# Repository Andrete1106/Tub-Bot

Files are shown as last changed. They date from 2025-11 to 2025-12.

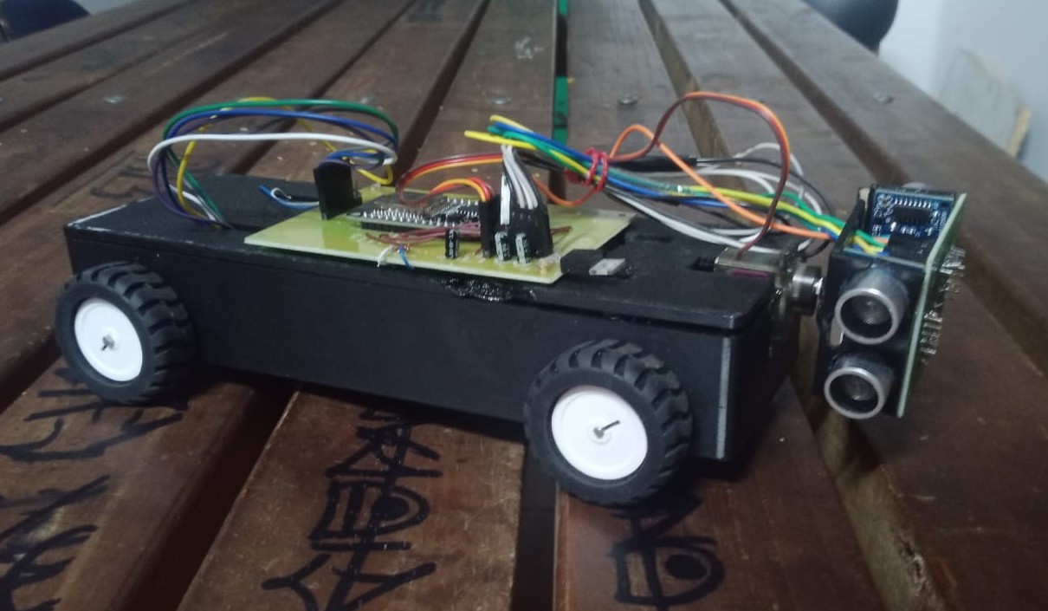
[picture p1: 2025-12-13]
Taller/Fotos y Videos/Fotos/WhatsApp Image 2025-12-12 at 5.25.53 PM.jpeg

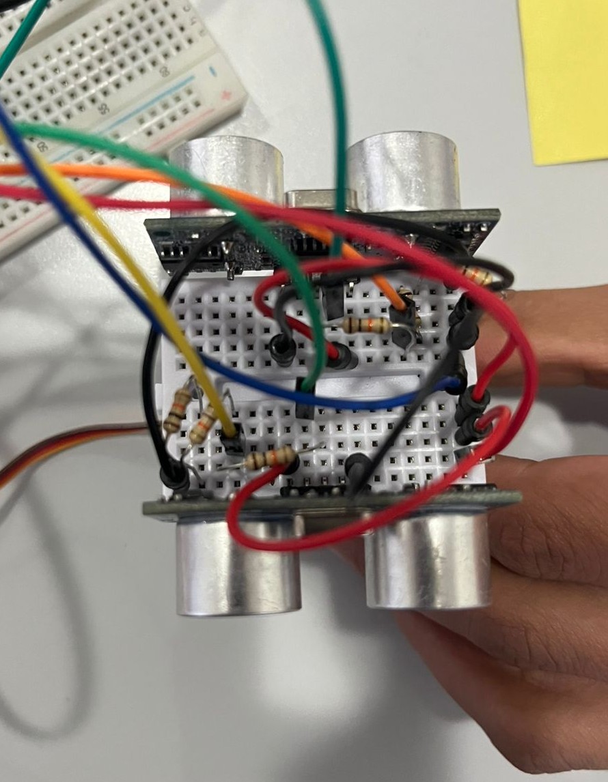
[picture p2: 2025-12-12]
Taller/Fotos y Videos/Fotos/WhatsApp Image 2025-12-07 at 12.38.35 PM (2).jpeg

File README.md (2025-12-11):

# Proyecto Tub-Bot
Repositorio para el Proyecto "Tub-Bot" correspondiente a las materias de:
- Introducción a Ingeniería Electrónica 
- Taller de Electrónica

**Universidad Nacional de Colombia**

## **Integrantes**
- Andres David Hincapié Álvarez (Ingeniería Electrónica)  
- Samuel Alejandro Bulla Fiquitiva (Ingeniería Electrónica)
- Juan Jose Aleman Martinez (Ingeniería Electrónica)
- Camilo Andrés Triana Ortiz (Ingeniería Mecatrónica)
- Ricardo Javier Rivas Sabogal (Ingeniería Electrónica)
- Luis Armando Berrocal Estrada (Ingeniería Electrónica)

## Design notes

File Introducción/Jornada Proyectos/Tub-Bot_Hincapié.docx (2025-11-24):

Título del proyecto | Tub-Bot
Autor(a) / correo / carrera que cursa ó Lista que incluya a las personas integrantes del equipo / correo / carrera que cursa Ejemplo: Patricia Perez Gabil Roso / pperezgar@unal… / Ingeniería civil | Juan Jose Aleman Martinez / jualemanm@unal.edu.co / Ingeniería Electrónica Samuel Alejandro Bulla Fiquitiva / sbullaf@unal.edu.co / Ingeniería Electrónica Ricardo Javier Rivas Sabogal / rrivass@unal.edu.co / Ingeniería Electrónica Luis Armando Berrocal Estrada / lberrocale@unal.edu.co / Ingeniería Electrónica Andrés David Hincapié Álvarez / anhincapiea@unal.edu.co / Ingeniería Electrónica

Resumen en un solo párrafo

(de 200 a 250 palabras)

El proyecto consiste en el desarrollo de un robot diseñado para desplazarse dentro de tuberías matrices y secundarias del sistema de acueducto, cuyo propósito es inspeccionar internamente la red y detectar, con alta precisión, grietas, fisuras o daños estructurales, sin realizar reparaciones directas. A diferencia de los métodos tradicionales basados en geófonos o georadares, que dependen del sonido del flujo de agua y presentan limitaciones frente a microfisuras o estructuras complejas, este prototipo permite observar el interior del conducto en condiciones sin flujo de agua, lo que incrementa la exactitud en la localización de fallas. El robot incorpora cámaras y sensores que generan un registro visual y digital del estado interno, facilitando que los equipos de acueducto planifiquen intervenciones más eficientes y eviten excavaciones innecesarias. Su capacidad de desplazamiento controlado ofrece una alternativa accesible frente a los robots modulares comerciales, que suelen tener altos costos y restricciones en diámetros menores a 100 mm. Gracias a su enfoque preventivo, este sistema mejora la gestión del mantenimiento, reduce el tiempo de diagnóstico y contribuye indirectamente a disminuir pérdidas de agua tratada al identificar oportunamente daños que, de no detectarse, podrían evolucionar en fugas mayores. En conjunto, el proyecto propone una solución tecnológica práctica, de bajo costo relativo y alineada con la necesidad de modernizar la infraestructura de inspección del acueducto de Bogotá.
Palabras clave | - Detección de daños - Inspección interna - Robot de tuberías - Tuberías matrices - Tuberías secundarias - Grietas - Fisuras - Microfisuras - Fugas - Agua potable - Acueducto - Desplazamiento controlado - Sensores - Cámara interna - Localización de averías - Diagnóstico - Sistema inteligente - Redes subterráneas - Mantenimiento preventivo - Pérdidas técnicas - Agua no contabilizada - Eficiencia operativa - Red de distribución - Bogotá - Inspección robotizada - Autonomía - Precisión

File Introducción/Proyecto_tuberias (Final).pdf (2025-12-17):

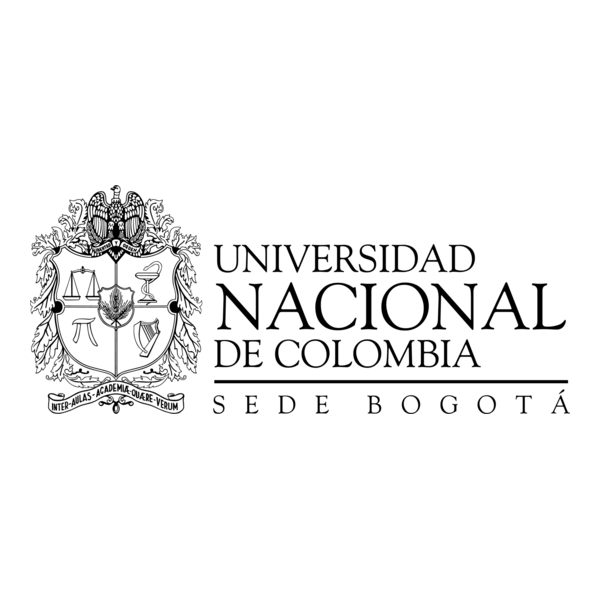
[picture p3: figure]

## SISTEMA INTELIGENTE EN DETECCION DE ´

DANOS EN TUBER ˜ | ÍAS

### Juan Aleman´

Andres Hincapi ´ | é

### Luis Berrocal Samuel Bulla Ricardo Rivas

### Universidad Nacional de Colombia

Introduccion a la ing. Electr ´ | onica ´

### Facultad de Ingenierıá Bogota D.C. ´

2025

Resumen—A partir del objetivo de desarrollo
sotenible numero seis, ´ | ”agua limpia y saneamien-
to” [1], pretendemos que por medio de nuestro prototipo, se logre implementar una metodologıá
mas efectiva en la detecci ´ | on de da ´ | nos en las redes ˜
de tuberıas locales, y asi mitigar el desperdicio de ´ agua en las ciudades y ofrecer un uso mas eficien- ´ te de este recurso; queremos que al introducir el dispositivo dentro de las tuberıas este sea capaz ´ de escanear las afectaciones y logre identificar la zona exacta en donde ocurrio el dano. ˜
I. Estado del Arte
Existen distintos sistemas los cuales buscan satisfacer la necesidad comun de identificar ´ la zona en la que una tubería se encuentra danada por lo que los hemos clasificado en tres ˜ grupos.
Sondas: Este sistema trata, en introducir un dispositivo que, generalmente se encuentra cableado semejante a un endoscopio por lo que no se facilita mucho su movilidad en entornos complejos y depende en gran medida de la longitud de sus cables en consecuencia ofrece una solucion parcial y bastante limitada. ´ Sensores independientes: Este sistema abarca bastantes tecnicas las cuales a par- ´ tir de variables analogicas como la detec- ´
cion ultras ´ | onica, la termograf ´ | ía infrarroja,
los rayos x e incluso las corrientes de Foucault ; son capaces de elaborar un modelo 3d de la tuberías, sin necesidad de ser destructivas por lo que facilita bastante los costes en reparacion,su desventaja radica ´ en su falta de precision en situaciones de ´ mayor profundidad y que se exponen al ruido/interferencias en el ambiente. Robots modulares: Estos sistemas toman grandes rasgos de los anteriores, con la ventaja de que ofrecen una mayor autonomía y mejor control de lo que está ocurriendo dentro del conducto,algunos ejemplos de ellos son el robot Pipe dream y el robot PIRATE quienes se adaptan a tubería y pueden desplazarse dentro de ella. Su mayor dificultad son los altos costos y su limitacion en cuanto a que tan ´
estrecho es el diametro de la tuber ´ | ía en
sí(<100mm)

II. Justificacion´
El prototipo permite reducir significativamente el desperdicio de agua en Bogotá
al localizar fugas y danos en las tuber ˜ | ías
con mayor rapidez y precision que las ´ tecnicas actuales. Al detectar los puntos ´ exactos de falla, se evitan excavaciones innecesarias y se logra un ahorro economico ´ directo para la Empresa de Acueducto, ademas de un importante beneficio am- ´ biental al evitar que se desperdicie tanta agua.Actualmente, la forma tradicional de reparar tuberías genera multiples proble- ´ mas a los habitantes de la ciudad: suspensiones del servicio que duran varios días, cierre prolongado de vías, aumento de los trancones y deterioro acelerado de las calles. Estas intervenciones afectan la movilidad, la calidad de vida y la imagen de la ciudad.Nuestro proyecto propone una solucion eficaz y de bajo costo, construida ´ con componentes disponibles localmente, que reduce drasticamente los tiempos y ´ costos de inspeccion. Al minimizar las ex- ´ cavaciones a ciegas, no solo se optimizan los recursos publicos, sino que se previe- ´ nen riesgos mayores como hundimientos, colapsos de redes e inundaciones en el sistema.

III. Problematica ´

En el 2024 en bogota se desperdiciaron ´ aproximadamente 89 millones de metros cubicos de agua potable , debido princi- ´ palmente a las conexiones defectuosas y a las tuberías danadas dentro de la red de ˜ acueducto de la ciudad, esta cifra equivale aproximadamente al consumo de agua de un mes en la ciudad por lo que su cifra es alarmante dentro de un contexto en el que el agua es un recurso limitado el cual por distintas circunstancias que se han presentando nuestros embalses han disminuido su densidad. El agua es un recurso renovable en la medida en que su uso no exceda la tasa de renovacion natu- ´ ral y de por sí nosotros los humanos dependemos en gran medida de este recurso para nuestra supervivencia meramente individual; nos beneficiamos principalmente de el agua dulce la cual representa solo 2.5% de la cantidad total terrestre ´ y de la cual no tenemos todo su acceso ya que el 68.7% de esa agua se encuentra congelada, el 30.1% es subterranea y ´ nos quedamos con un restante global de aproximadamente 1.2% que mantiene a 8 millones de personas con vida por lo que es una problematica bastante seria el ´ hecho de que por factores estrategicos y ´

logísticos en la red de distribucion del ´ agua estemos presentando tantas perdidas ´ de un recurso tan valioso como este.
La verdadera problematica no radica en ´ que las tuberías se rompan ya que no necesariamente dicho rompimiento puede deberse a la obsolescencia del material, tambien puede presentarse por movi- ´ mientos en la tierra o por golpes de ariete al tratarse de un material el cual está expuesto a un flujo y friccion constante ´ es casi inevitable que se presente algun´ desgaste, la problematica que hemos ana- ´ lizado esta inmersa en el hecho de las ´ practicas actuales no generan la suficiente ´ eficacia como para detectar si una tubería se encuentra rota, en bogota se utilizan ´
comunmente los ge ´ | ofonos y georadares ´
los cuales por medio del sonido que genera el agua en una fuga identifican donde se encuentra el dano a la red, ahora bien ˜ estas tecnicas no son lo suficientemente ´ buenas al momento en que se presentan microfisuras que a su vez generan goteos o al momento en que una fuga posee un sistema complejo en su deteccion ya que un ´ sonido no es una senal tan exacta si se tra- ˜ ta de una red mas compleja que involucra ´
mas tuber ´ | ías.Ahora bien ¿como entonces

se disena un sistema inteligente capaz de ˜

solucionar un problema complejo como

el desperdicio de agua potable a traves´

del dano en una tuber ˜ | ía subterranea?. ´
IV. | Marco teorico ´
La inspeccion del estado estructural de las ´ tuberías de agua potable es un componente esencial para la empresa de acueducto y alcantarillado de Bogota,la cual ´ cuenta con líneas principales y secundarias de diametros superiores a 6 pulgadas. ´ Estas tuberías estan sometidas a presio- ´ nes variables, cargas del terreno, procesos de corrosion, vibraciones y desgastes del ´ material, factores que pueden ocasionar danos en los conductos,facilitando las fil- ˜ traciones de agua . La deteccion temprana ´
de estos danos permite reducir p ˜ | erdidas ´
de agua, optimizar el mantenimiento y garantizar la continuidad del servicio. Sin embargo, muchas de las fallas internas no son visibles, al encontrarse enterradas a una profundidad aproximada de un metro , se hace necesaria la inspeccion´ directa dentro del conducto. Aunque exis-
ten metodos de inspecci ´ | on externa como ´
medicion de presi ´ | on, mapeo ac ´ | ustico o ´
sondas con camaras introducidas ,estas ´ tecnicas tienen limitaciones, especialmen- ´ te en tuberías enterradas. Por esta razon, ´ en nuestro proyecto planteamos recurrir a la apertura controlada de un tramo de
tubería ,fuera de operacion y as ´ | í intro-
ducir nuestro dispositivo de exploracion´ interna.Para ello contamos con dos formas de recolectar informacion dentro del con- ´
ducto una es a traves de un m ´ | odulo de ´
camara, la cual vigilar ´ | a durante el tramo ´
de recorrido ,si se observa algun da ´ | no evi- ˜
dente y de facil identificaci ´ | on; otra es por ´
medio de sensores ultrasonido los cuales son capaces de detectar pequenas pertur- ˜
baciones en el diametro de la tuber ´ | ía, esto
es posible gracias a que en su funcionamiento emiten y captan senales de sonido ˜ las cuales rebotan contra las paredes del conducto ,si hablamos de una senal cons- ˜ tante(diametro constante)los valores que ´ arrojen estos sensores deben ser iguales durante el tramo donde se escanee, de no ser así indica que el conducto pre-
senta una perturbacion la cual est ´ | a in- ´
terviniendo y que generalmente representa un dano en su estructura.Todo este ˜ procesamiento de informacion va a ser ´ transportada vía cable,la cual conectara al ´ prototipo con un servidor el cual estará recibiendo la transmision de la informa- ´
cion en tiempo real y por el cual tambi ´ | en´
se podra dar ´ | ordenes de movilizaci ´ | on al ´
prototipo una vez dentro. La transmision´ de informacion v ´ ía cable ofrece algunas ventajas ,una de ellas es su capacidad para ofrecer un mejor transporte de las senales recolectadas sin que el ruido ex- ˜ terno las afecte y se pierda informacion´ en el trayecto, si hablamos de un ambiente cerrado, hermetico y que en muchos casos ´ se compone de una estructura metalica, ´ se crea una jaula de faraday la cual im-
posibilita la transmision de informaci ´ | on´
por senales electromagn ˜ | eticas por lo que ´
la alternativa bluetooth no sería la mas´ adecuada en estos casos. Finalmente todo se encontrara en un solo modelo el cual integrara ambas formas de recolectar la ´
informacion, mientras que el m ´ | | odulo de ´
la camara recolecta la informaci ´ | | on visual ´
,el modulo de sensor ultrasonico recoge la ´
informacion estructural de la tuber ´ | | ía, am-
bos tipos de datos facilitaran abarcar m ´ | as´

terreno en cuanto al tipo de dano que se ˜ presenta,ya que en realidad no se puede determinar facilmente la causa si solo se ´ tiene un vistazo inicial del conducto. La geometría cilíndrica de un tubo no permite un desplazamiento sencillo dentro de este, si se piensa de la forma tradicional como en una superficie plana,cuenta con varias intersecciones y cambios en
los diametros de las tuber ´ | ías por lo que
se necesita repensar un modelo el cual sea capaz de adaptarse a estos cambios de diametro y puede flexionarse en las ´ diferentes intersecciones, de lo contrario no sobrevivira a este tipo de condiciones. ´
V. Hipotesis ´
A partir de un prototipo que integre una esp32-cam y un par de sensores ultrasonido,que envían informacion v ´ ía cable a un servidor capaz de interpretar y transmitir datos en tiempo real;se logre implementar una metodología mas eficiente en la ´
deteccion de da ´ | nos a las redes de tuber ˜ | ía
en Bogota y en consecuencia se disminuya ´ el desperdicio de agua en la ciudad.
VI. | Objetivo general
Identificar | eficazmente | los | danos | en ˜

una tubería implementando un prototipo

inteligente

VI-A. Objetivos especificos:
1. Localizar la zona en donde se encuentra la avería
2. Desplazarse de forma controlada por el conducto
3. Comunicar el dano encontrado ˜

VII. Metodología
El desarrollo del prototipo se llevo a cabo ´ mediante un proceso iterativo, en el cual fue necesario ajustar varias decisiones de disenõ debido a las condiciones físicas y operativas de una tubería de seis pulgadas. Inicialmente, se planteo construir un modelo compac- ´ to que pudiera desplazarse facilmente por el ´ interior del conducto; sin embargo, durante las primeras etapas se presentaron percances relacionados con las dimensiones internas, el espacio util disponible y la interferencia ge- ´ nerada por elementos como cables, sensores y mecanismos de movilidad. Estos inconvenientes obligaron a redisenar la estructura y a ˜ reorganizar la distribucion de los componentes ´ electronicos.Una de las decisiones clave fue ´ la incorporacion de una ESP32-CAM como ´ unidad principal de captura de imagenes. Este ´
modulo se seleccion ´ | o debido a que integra la ´
camara OV2640, lo que facilit ´ | o su implementa- ´
cion sin necesidad de m ´ | odulos adicionales. Su ´
tamano compacto, conectividad inal ˜ | ambrica y ´
facilidad de programacion permitieron agilizar ´ la etapa de pruebas y optimizar la adquisicion´ de imagenes durante el desplazamiento del ´ prototipo. Para la deteccion de perturbaciones ´
en el diametro interno de la tuber ´ | | ía, se integra-
ron dos sensores ultrasonicos montados sobre ´ un servo motor capaz de ejecutar un giro de
180°. Durante la fase de diseno se evidenci ˜ | ó
que, al girar el sensor en una superficie circular, se generaban puntos ciegos que impedían obtener una lectura completa del entorno. Por esta razon, fue necesario incluir dos sensores ´ en vez de uno, ubicados de forma simetrica, ´ de manera que el barrido cubriera totalmente
la seccion del conducto. Esta configuraci ´ | | on´
permitio obtener mediciones m ´ | as estables y ´
precisas en cada rotacion. ´
El sistema de movilidad del prototipo se di-
senõ mediante cuatro motores de tracci ´ | on, ins- ´
talados en configuracion tipo veh ´ | ículo para
garantizar un desplazamiento estable dentro de la tubería. Cada par de motores fue controlado mediante un driver L298N, permitiendo así la manipulacion independiente del movi- ´ miento.Con el fin de optimizar el desempenõ general del sistema, se decidio implementar ´ dos unidades ESP32 independientes: una dedi-
cada unicamente a la c ´ | amara y la transmisi ´ | on´
de imagenes, y otra encargada del control de ´ motores, sensores ultrasonido y servo. Esta se-
paracion permiti ´ | o distribuir la carga de proce- ´
samiento, evitando saturacion en un ´ | unico mi- ´
crocontrolador y logrando un funcionamiento
mas fluido, especialmente en la transmisi ´ | on de ´
vídeo.
Todos los componentes electronicos se inte- ´ graron en una placa PCB disenada a medida, ˜ lo que permitio reducir el cableado, asegurar ´ conexiones mas firmes y facilitar el ensamblaje ´ dentro del prototipo. Finalmente, el chasis fue impreso en 3D utilizando filamento PETG, material elegido por su alta resistencia mecanica, ´ durabilidad, tolerancia a la humedad y estabilidad dimensional, características esenciales para operar dentro de un entorno cerrado y
potencialmente humedo como una tuber ´ | | ía de
agua potable.

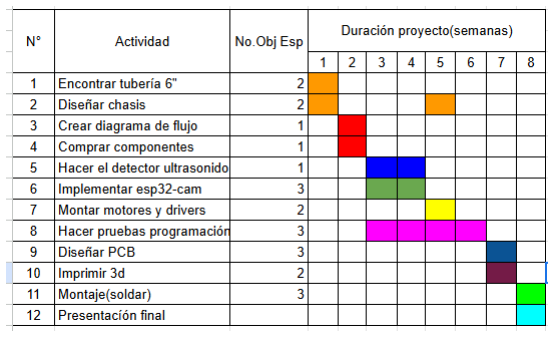
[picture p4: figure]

VIII. Cronograma de actividades

Referencias

[1] O. | de | las | Naciones | Unidas. | (2015) | Agua
y saneamiento. Accedido: 10/03/2025. [Online]. Available: https://www.un.org/sustainabledevelopment/es/water-and-sanitation/ (https://www.un.org/sustainabledevelopment/es/water-and-sanitation/)
[2] R. USA. (2025) Laser pipe profiling applications. Accedido: 10/03/2025. [Online]. Available: https: //rauschusa.com/products/cctv-inspection/availabl e-applications/laser-pipe-profiling/ (https://rauschusa.com/products/cctv-inspection/available-applications/laser-pipe-profiling/)
[3] JettyRobot. (2025) Robotic solutions for pipe inspection. Accedido: 10/03/2025. [Online]. Available: https://www.jettyrobot.com/
[4] D. Henares. (2023) Robot de inspeccion de ca ´ | ner ˜
| | | | | | ías.
Accedido: 10/03/2025. [Online]. Available: https: //www.desatascoshenares.com/blog/robot-inspeccio n-canerias/ (https://www.desatascoshenares.com/blog/robot-inspeccion-canerias/)
[5] A. M. de Bogota. (2024) ´

Índice de perdida o ´
desperdicio de agua en bogota. Accedido: 10/03/2025. ´ [Online]. Available: https://bogota.gov.co/mi-ciudad/habitat/indice-de-perdida-o-desperdicio-agua-en-b ogota-es-estandar-acueducto (https://bogota.gov.co/mi-ciudad/habitat/indice-de-perdida-o-desperdicio-agua-en-bogota-es-estandar-acueducto)
[6] U. de los Andes. (2023) 37% del agua en bogot
| | | | | | á
se pierde. Accedido: 10/03/2025. [Online]. Available: https://www.uniandes.edu.co/es/noticias/ingenieria/37-del-agua-en-bogota-se-pierde (https://www.uniandes.edu.co/es/noticias/ingenieria/37-del-agua-en-bogota-se-pierde)
[7] E. de Acueducto y Alcantarillado de Bogota. (2024) ´ Mapa del acueducto. Accedido: 10/03/2025. [Online]. Available: https://www.acueducto.com.co/wps/portal/EAB2/Home/acueducto-y-alcantarillado/la-infraestructuraAcueducto/Mapa-Acueducto (https://www.acueducto.com.co/wps/portal/EAB2/Home/acueducto-y-alcantarillado/la-infraestructuraAcueducto/Mapa-Acueducto)
[8] F. Aquae. (2023) ¿que cantidad de agua dulce hay en ´ el planeta? Accedido: 10/03/2025. [Online]. Available: https://www.fundacionaquae.org/que-cantidad-de-agua-dulce-hay-en-el-planeta/ (https://www.fundacionaquae.org/que-cantidad-de-agua-dulce-hay-en-el-planeta/)

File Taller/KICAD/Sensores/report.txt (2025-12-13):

Actualizado Conn_01x05 de J4_coneccion_esp a J4_coneccion_esp1.
Actualizado Conn_01x02 de J_pwr a J_pwr1.
Anotación completada.
Anotación completada.

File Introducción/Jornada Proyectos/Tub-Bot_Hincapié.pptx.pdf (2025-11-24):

# Introducción

El sistema de acueducto de Bogotá enfrenta un desgaste progresivo debido a la antigüedad de gran parte de su infraestructura, lo que favorece la aparición de grietas, fisuras y deterioros internos que suelen pasar desapercibidos hasta convertirse en fugas significativas. Los métodos tradicionales de inspección —como geófonos o georadares— presentan limitaciones importantes, especialmente en el caso de microfisuras, tuberías de difícil acceso o condiciones sin flujo de agua, donde la detección se vuelve imprecisa y lenta. Esta situación contribuye a un incremento en las pérdidas técnicas de agua potable, que representan un problema operativo y económico para la ciudad, pues la identificación tardía de fallas obliga a intervenciones más costosas y a excavaciones que afectan la movilidad y el entorno urbano. Frente a este escenario, el proyecto propone el desarrollo de un robot capaz de desplazarse dentro de tuberías matrices y secundarias para inspeccionarlas visualmente desde el interior, registrando daños (se usa sin flujo de agua) y sin reemplazar directamente los métodos de reparación. Este enfoque ofrece una alternativa más accesible que los robots comerciales de alto costo, un tamaño adaptado para tuberías más reducidas al tiempo que mejora la precisión del diagnóstico y apoya la toma de decisiones antes de que las averías evolucionen en fugas mayores. En conjunto, el proyecto busca fortalecer las estrategias de mantenimiento preventivo y contribuir a la reducción de pérdidas de agua en la ciudad mediante una inspección más eficiente y tecnológicamente viable.

# Objetivos

Objetivo general
Desarrollar un sistema robótico capaz de identificar de manera eficiente y precisa los daños internos en tuberías matrices y secundarias, con el fin de mejorar la detección temprana de averías y apoyar la reducción de pérdidas de agua potable en Bogotá.
Objetivos específicos
1. Diseñar un robot capaz de desplazarse de forma estable dentro de tuberías matrices y secundarias.
2. Detectar y registrar visualmente grietas, fisuras y daños internos.
3. Localizar con precisión la posición de las averías para facilitar intervenciones externas.
4. Reducir el tiempo y la dificultad de las inspecciones respecto a métodos tradicionales y mejorar la eficiencia del diagnóstico de daños en la red de acueducto
5. Contribuir a la disminución de pérdidas técnicas de agua potable en Bogotá mediante la detección temprana de averías
6. Proponer una solución de bajo costo relativo, tamaño adaptado a las necesidades.

# Resultados Esperados

# Fractal

# Errores

A lo largo del desarrollo del proyecto hemos identificado varios errores que han influido en el avance y el alcance final de la propuesta. En primer lugar, planteamos un proyecto demasiado ambicioso, especialmente al intentar cubrir tuberías con desviaciones verticales, lo cual superaba nuestra capacidad técnica y los recursos disponibles, obligándonos a reducir su alcance hacia escenarios más realistas. También seleccionamos algunos materiales que, aunque parecían adecuados, no se adaptaron correctamente al prototipo debido a limitaciones de espacio que no habíamos contemplado, sumado a que omitimos la compra de adaptadores esenciales para integrar componentes específicos. Otro error importante fue la elección de un microcontrolador incompatible con otros elementos electrónicos, generando conflictos de conexión y alimentación que no previmos en la planeación inicial. Además, partimos de la idea equivocada de que la electrónica era un área de aplicación limitada, lo que nos llevó a subestimar la complejidad real de integrar sensores, motores y controladores en un espacio reducido. A esto se añadió que subestimamos los tiempos necesarios para desarrollar el proyecto con calma, lo que provocó retrasos y presión innecesaria. Finalmente, durante las primeras etapas tuvimos dificultades para organizarnos y entendernos como equipo, lo que afectó la coordinación y la toma de decisiones. Todos estos aspectos nos permitieron reconocer la importancia de una planificación detallada, una comunicación efectiva y una evaluación técnica más rigurosa desde el inicio.

# Tub-Bot

Juan Jose Aleman Martinez
jualemanm@unal.edu.co

Andrés David Hincapié Álvarez anhincapiea@unal.edu.co

Samuel Alejandro Bulla Fiquitiva sbullaf@unal.edu.co

Luis Armando Berrocal Estrada lberrocale@unal.edu.co

Ricardo Javier Rivas
Sabogal
rrivass@unal.edu.co
- Detección precisa de daños internos:
El robot permitirá identificar grietas, fisuras y deterioros en tuberías matrices y secundarias, incluso sin flujo de agua.
- Localización exacta de averías:
Se espera obtener una ubicación clara y puntual de los daños para facilitar intervenciones y evitar excavaciones innecesarias.
- Registro visual y digital confiable:
El sistema generará imágenes y datos que documenten el estado interno de la red y mejoren la toma de decisiones.
- Prototipo funcional y eficiente:
El robot ofrecerá desplazamiento estable, reducción de tiempos de inspección y una alternativa de bajo costo frente a equipos comerciales.

# Fractal

## Jornada de Proyectos y Prototipos

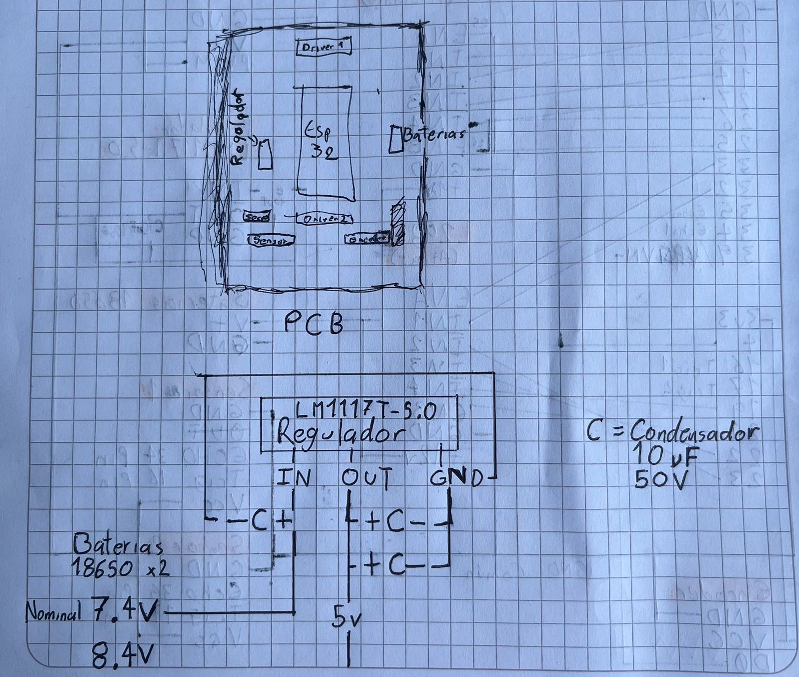
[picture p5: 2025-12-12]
Taller/Fotos y Videos/Fotos/WhatsApp Image 2025-12-07 at 12.38.35 PM.jpeg

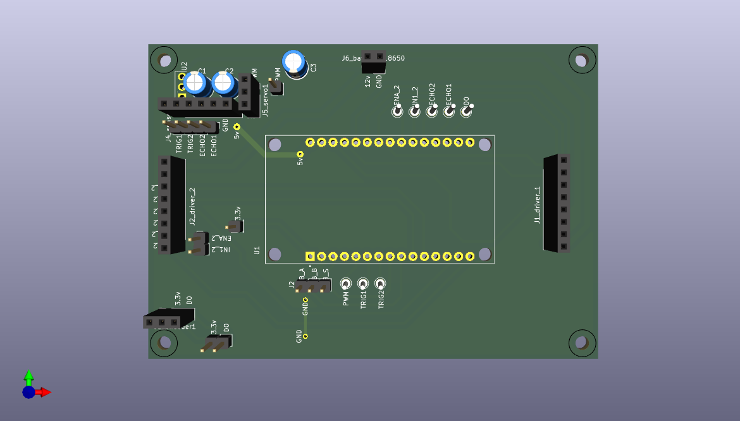
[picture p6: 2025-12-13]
Taller/KICAD/Principal/Pcb_Principal.png

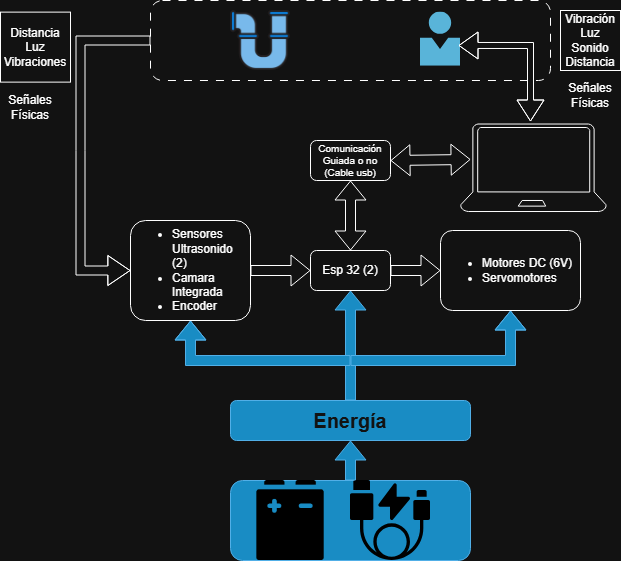
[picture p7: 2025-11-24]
Taller/Diagramas/Diagrama Caja Negra.png

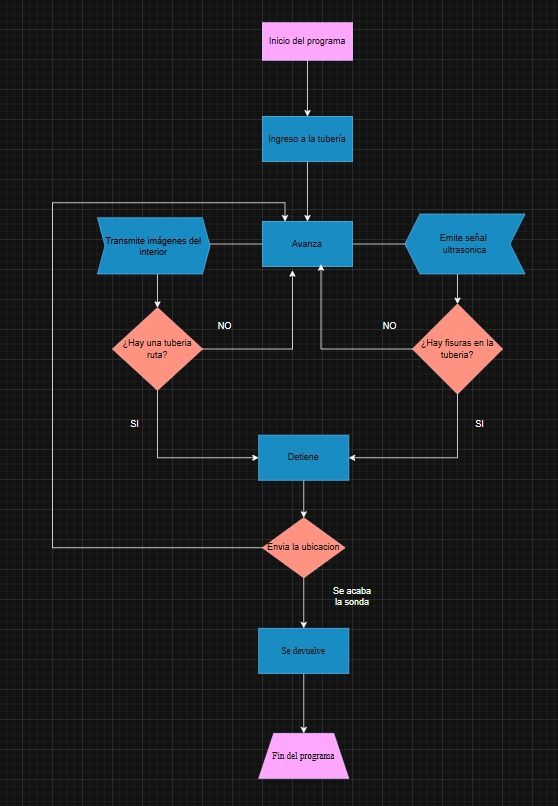
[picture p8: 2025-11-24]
Taller/Diagramas/Diagrama Flujo.jpg

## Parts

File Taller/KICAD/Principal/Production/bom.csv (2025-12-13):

Designator | Footprint | Quantity | Value | LCSC Part #
C1, C2, C3 | CP_Radial_D5.0mm_P2.50mm | 3 | C_Polarized
J1_DRIVER_1, J2_DRIVER_2 | PinSocket_1x08_P2.54mm_Vertical | 2 | Conn_01x08
J3_ENCODER1, J5_SERVO1 | PinSocket_1x03_P2.54mm_Vertical | 2 | Conn_01x03
J4_SENSORES1 | PinSocket_1x06_P2.54mm_Vertical | 1 | Conn_01x06
J6_BATERIAS_18650 | PinSocket_1x02_P2.54mm_Vertical | 1 | Conn_01x02
U1 | MODULE_ESP32_DEVKIT_V1 | 1 | ESP32-DEVKIT-V1
U2 | SIPAK_Vertical | 1 | LM1117DT-5.0

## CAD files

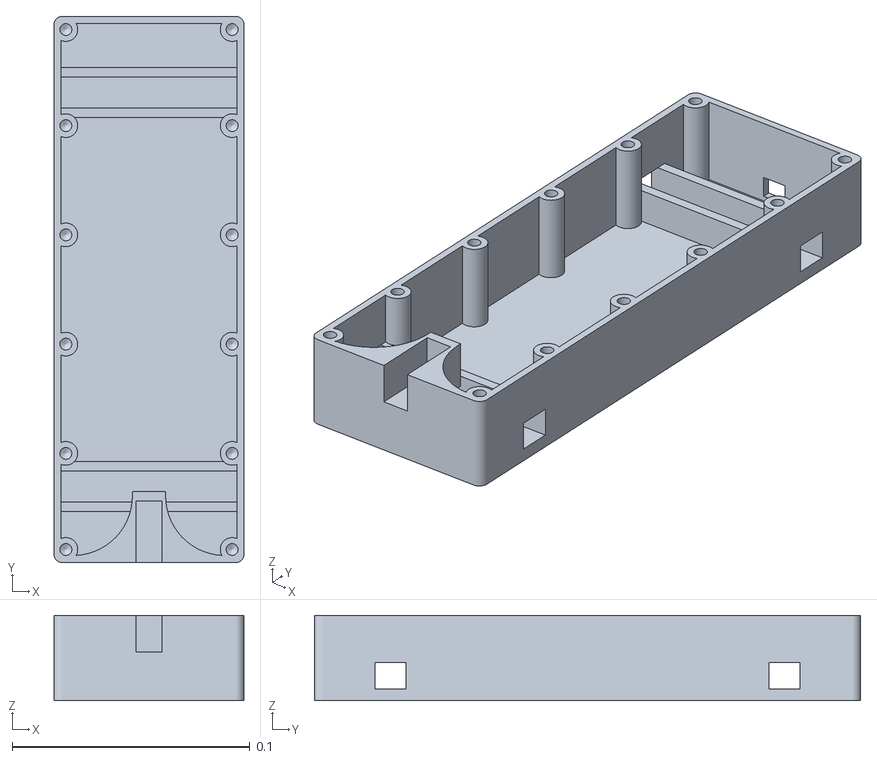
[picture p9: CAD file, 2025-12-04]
Taller/Diseño/Case/Cuerpo-Carcaza.stl
0.08 x 0.23 x 0.036

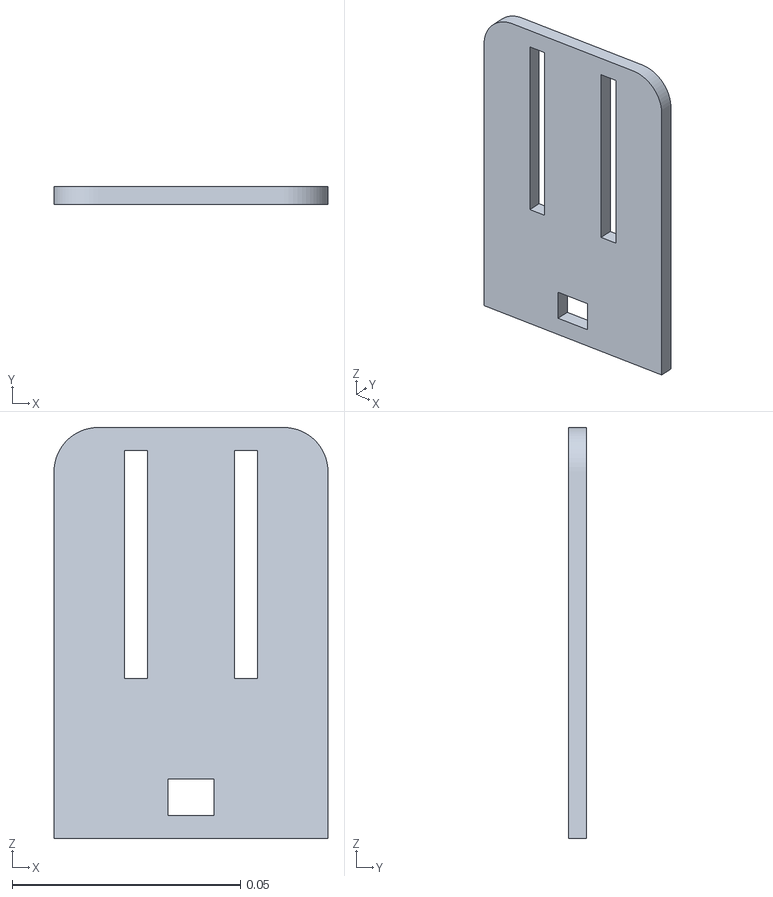
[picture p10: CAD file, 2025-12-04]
Taller/Diseño/Case/EncajeESP32.stl
0.06 x 0.004 x 0.09

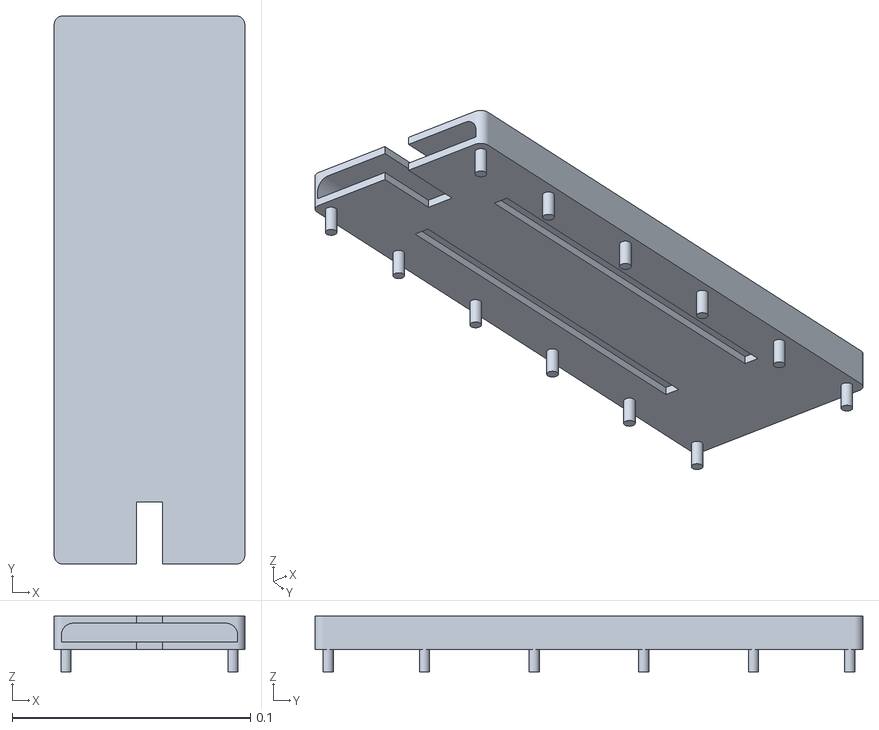
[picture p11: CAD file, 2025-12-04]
Taller/Diseño/Case/Tapa.stl
0.08 x 0.23 x 0.0235

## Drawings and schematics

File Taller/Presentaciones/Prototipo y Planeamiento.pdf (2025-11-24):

# PROYECTO FINAL

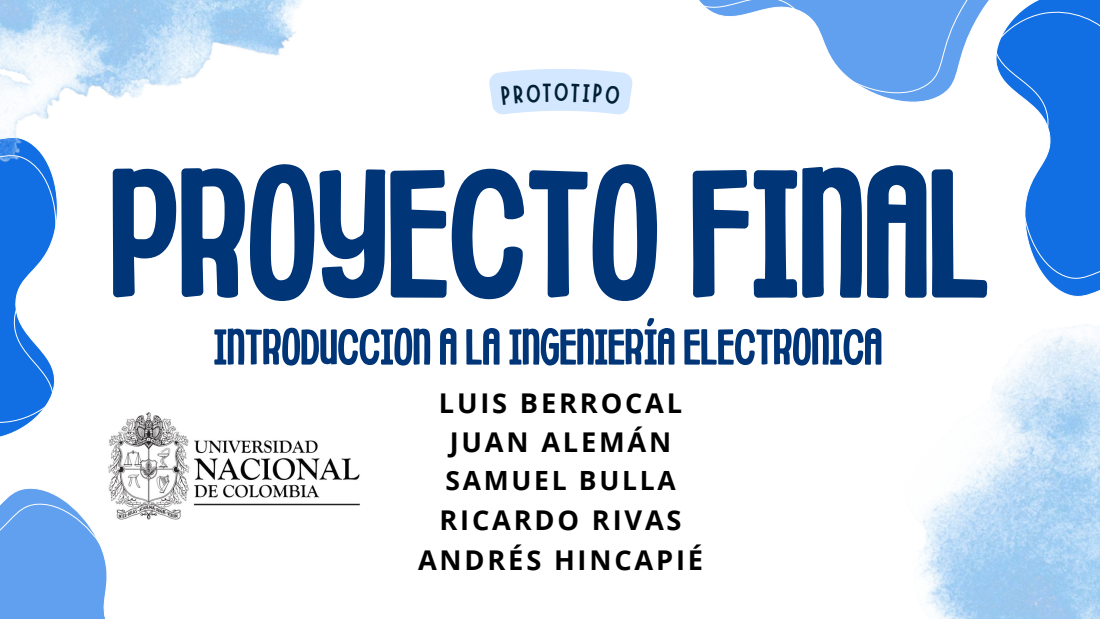
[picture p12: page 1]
INTRODUCCIONALAINGENIERÍAELECTRONICA; PROTOTIPO; LUIS BERROCAL JUAN ALEMÁN SAMUEL BULLA RICARDO RIVAS ANDRÉS HINCAPIÉ

# RESUMEN DE CONTENIDOS

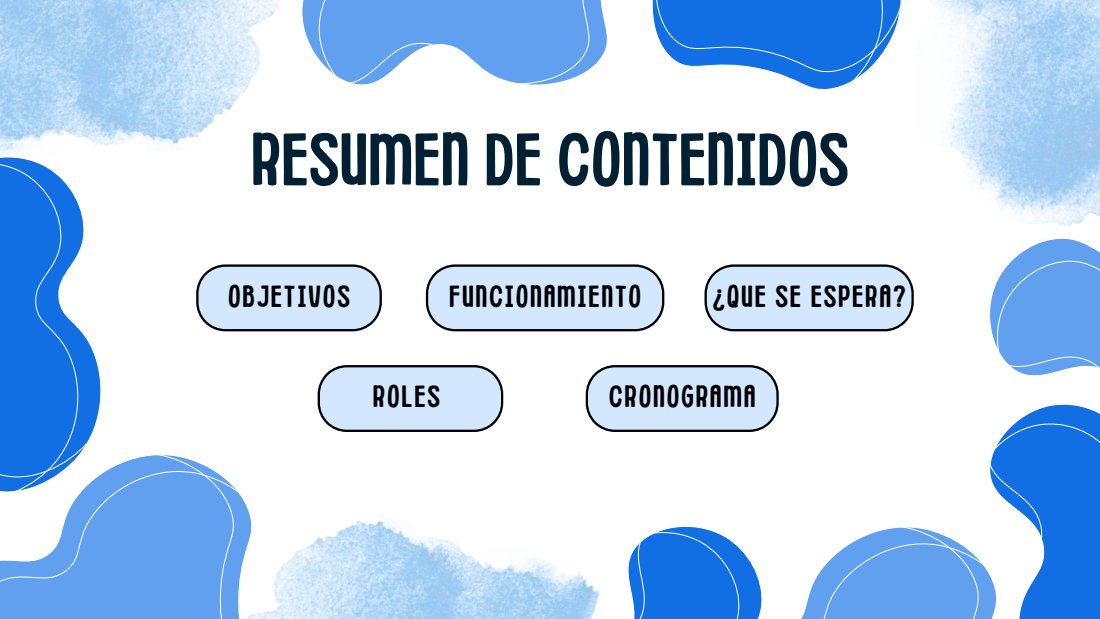
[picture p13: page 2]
ROLES; OBJETIVOS; FUNCIONAMIENTO; ¿QUE SE ESPERA?; CRONOGRAMA

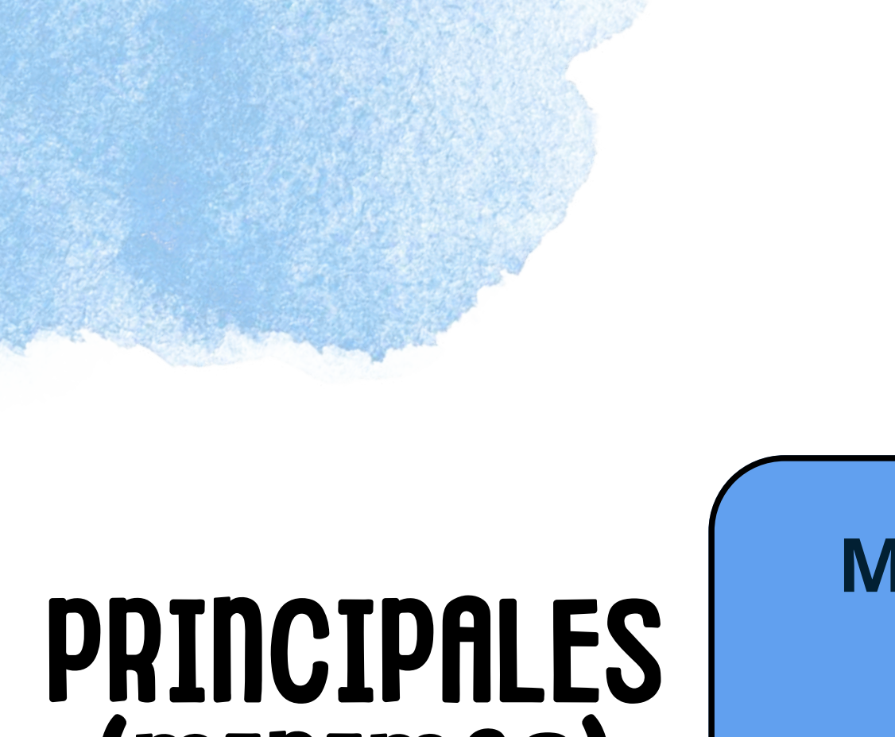
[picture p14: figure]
PRINCIPALES
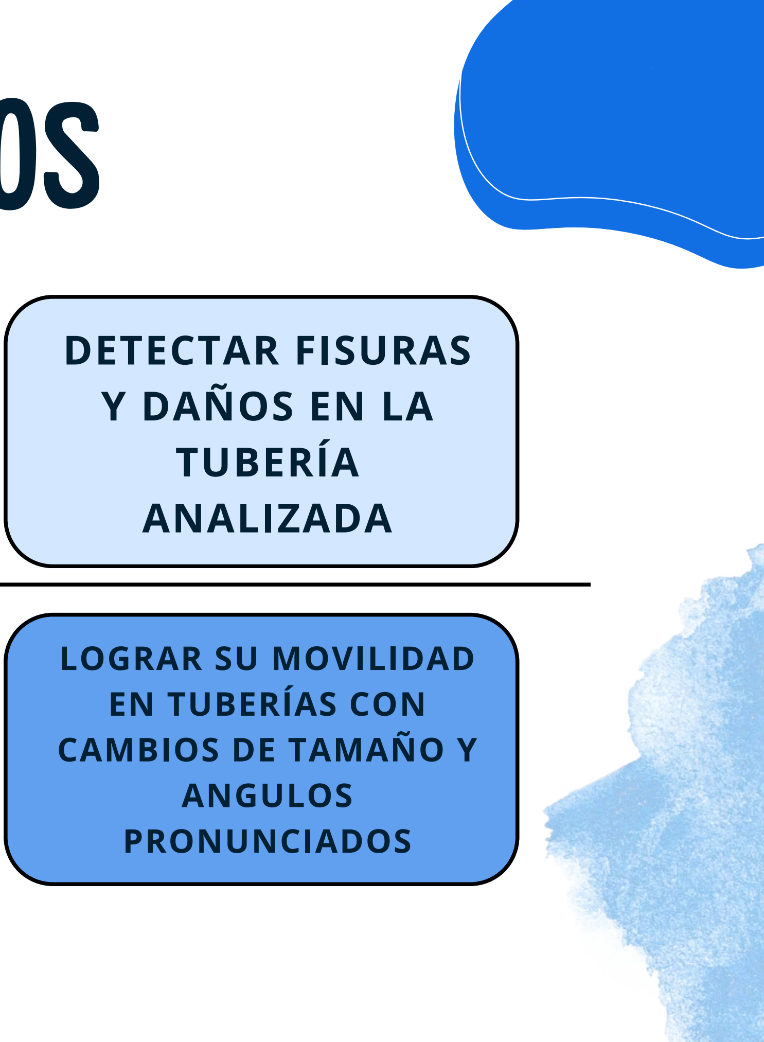
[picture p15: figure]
LOGRAR SU MOVILIDAD EN TUBERÍAS CON CAMBIOS DE TAMAÑO Y ANGULOS PRONUNCIADOS; DETECTAR FISURAS Y DAÑOS EN LA TUBERÍA ANALIZADA

# OBJETIVOS

## OPTIMIZAR LA ENERGÍA PARA SU FUNCIONAMIENTO

## MOVILIZARSE POR LA TUBERÍA

# (MINIMOS)

# SECUNDARIOS

# FUNCIONAMIENTO

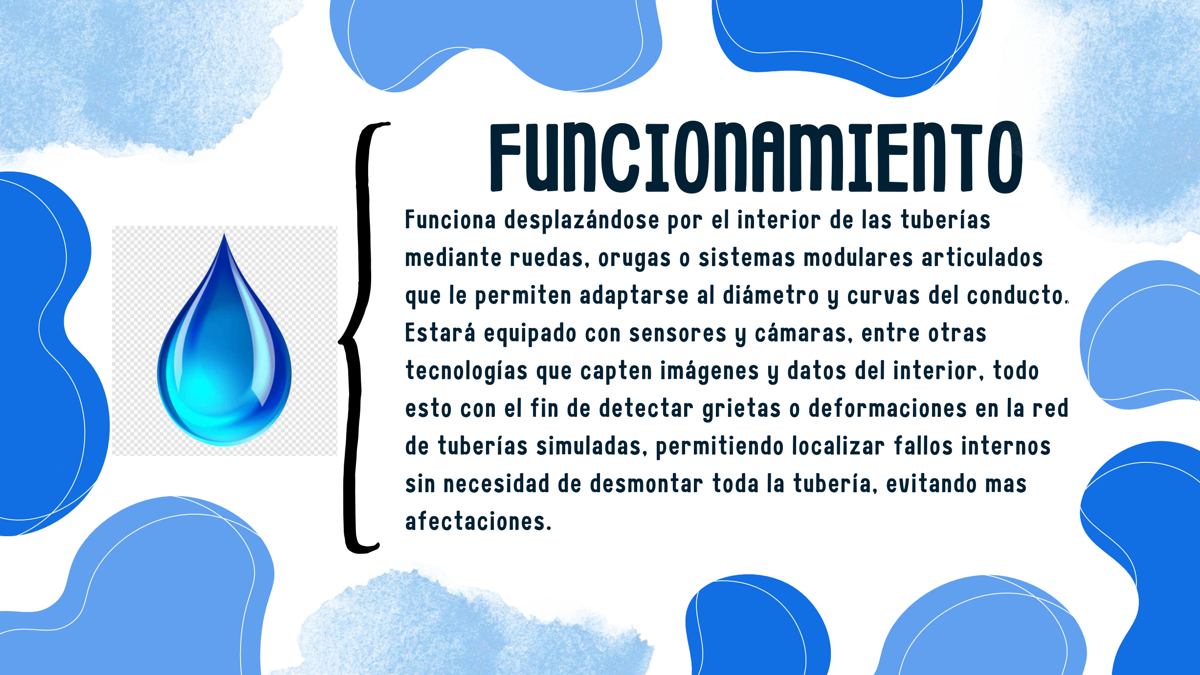
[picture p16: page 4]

Funciona desplazándose por el interior de las tuberías mediante ruedas, orugas o sistemas modulares articulados que le permiten adaptarse al diámetro y curvas del conducto. Estará equipado con sensores y cámaras, entre otras tecnologías que capten imágenes y datos del interior, todo esto con el fin de detectar grietas o deformaciones en la red de tuberías simuladas, permitiendo localizar fallos internos sin necesidad de desmontar toda la tubería, evitando mas afectaciones.

# ¿QUE ESPERAMOS MOSTRAR?

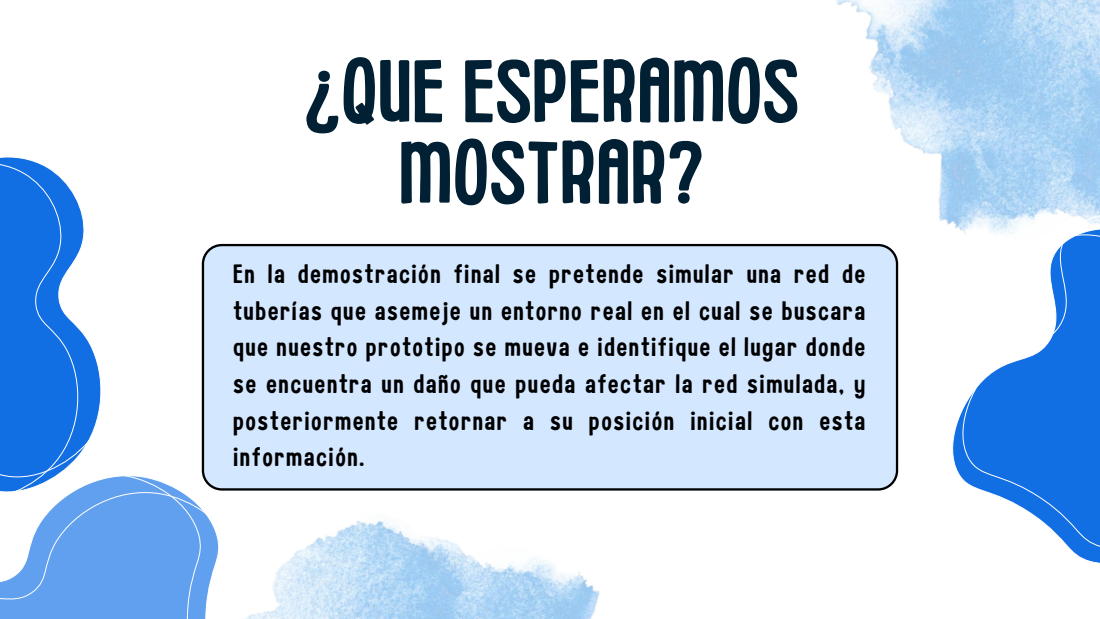
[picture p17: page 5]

En la demostración final se pretende simular una red de
tuberías que asemeje un entorno real en el cual se buscara
que nuestro prototipo se mueva e identifique el lugar donde
se encuentra un daño que pueda afectar la red simulada, y
posteriormente retornar a su posición inicial con esta
información.

# ROLES EQUIPO

LUIS BERROCAL | JUAN ALEMÁN
RICARDO RIVAS | ANDRÉS HINCAPIE

GABRIEL

Coordinador: Integrar de la mejor manera las habilidades del equipo, solucionar las posibles diferencias a lo largo del proyecto y apoyar las diferentes áreas de trabajo con el fin de llevar un correcto avance

Investigador: consultar las posibles tecnologías y/o herramientas que se puedan aplicar a lo largo del desarrollo del proyecto, llevando estos conocimientos de la teoría a la practica

Diseño de estructura y funcionamiento: aportar en la impresión de partes necesarias para la construcción del prototipo y todo lo relacionado a la parte mecánica del dispositivo

Ensamblaje del robot y del entorno simulado: Colaborar en el diseño, fabricación y ensamblaje del robot y del entorno que usaremos para simular las posibles situaciones.

Ensamblaje electrónico: Proceso de unir componentes en una placa de circuito impreso (PCB) para crear un dispositivo funcional, que incluye soldadura, montaje de componentes y pruebas finales

Redactor de informes: redactar los informes en donde se evidencie lo trabajado por el grupo a lo largo de la semana, incluyendo avances, problemas o cambios que vayan surgiendo mientras se desarrolla la idea.

SAMUEL BULLA

# CRONOGRAMA

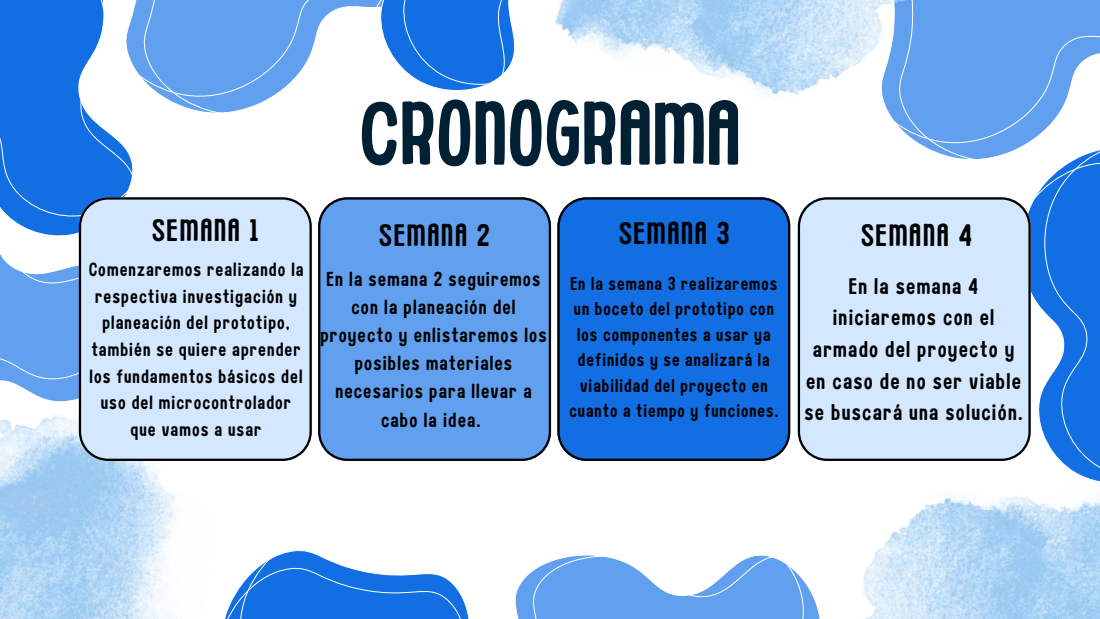
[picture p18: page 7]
SEMANA 1; SEMANA 2; SEMANA 3; SEMANA 4

Comenzaremos realizando la respectiva investigación y

En la semana 2 seguiremos
con la planeación del
proyecto y enlistaremos los
posibles materiales
necesarios para llevar a
cabo la idea.

En la semana 3 realizaremos
un boceto del prototipo con
los componentes a usar ya
definidos y se analizará la
viabilidad del proyecto en
cuanto a tiempo y funciones.

En la semana 4
iniciaremos con el
armado del proyecto y
en caso de no ser viable
se buscará una solución.

planeación del prototipo, también se quiere aprender los fundamentos básicos del uso del microcontrolador que vamos a usar

# CRONOGRAMA

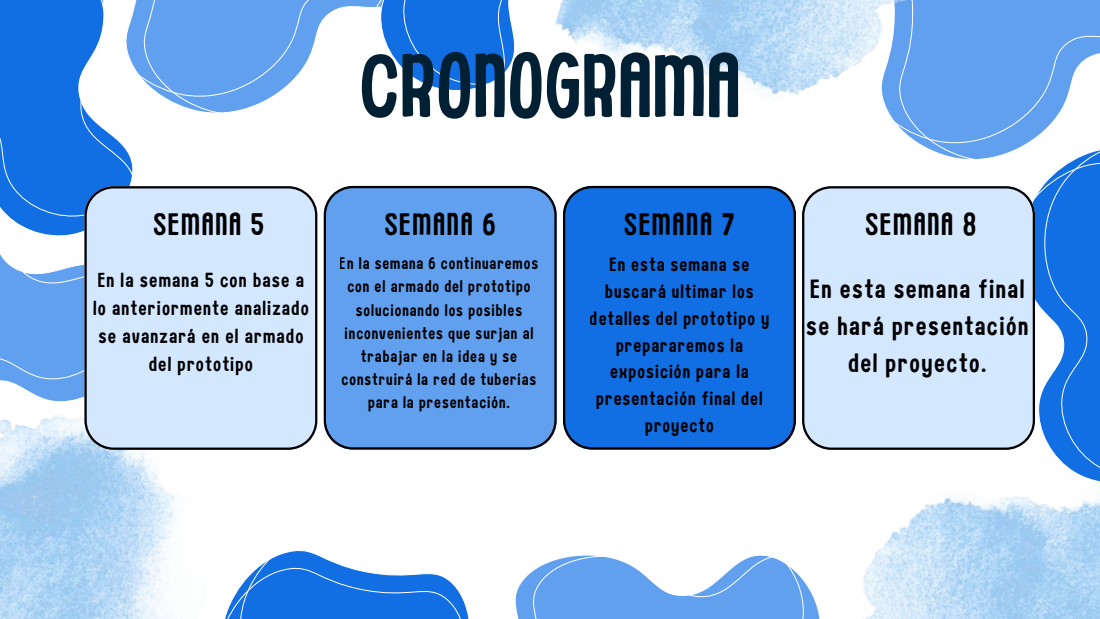
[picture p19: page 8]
SEMANA 5; SEMANA 6; SEMANA 7; SEMANA 8; En la semana; 5 con base a

En la semana 6 continuaremos
con el armado del prototipo
solucionando los posibles
inconvenientes que surjan al
trabajar en la idea y se
construirá la red de tuberías
para la presentación.

En esta semana se
buscará ultimar los
detalles del prototipo y
prepararemos la
exposición para la
presentación final del
proyecto

lo anteriormente analizado
se avanzará en el armado
del prototipo

En esta semana final
se hará presentación
del proyecto.

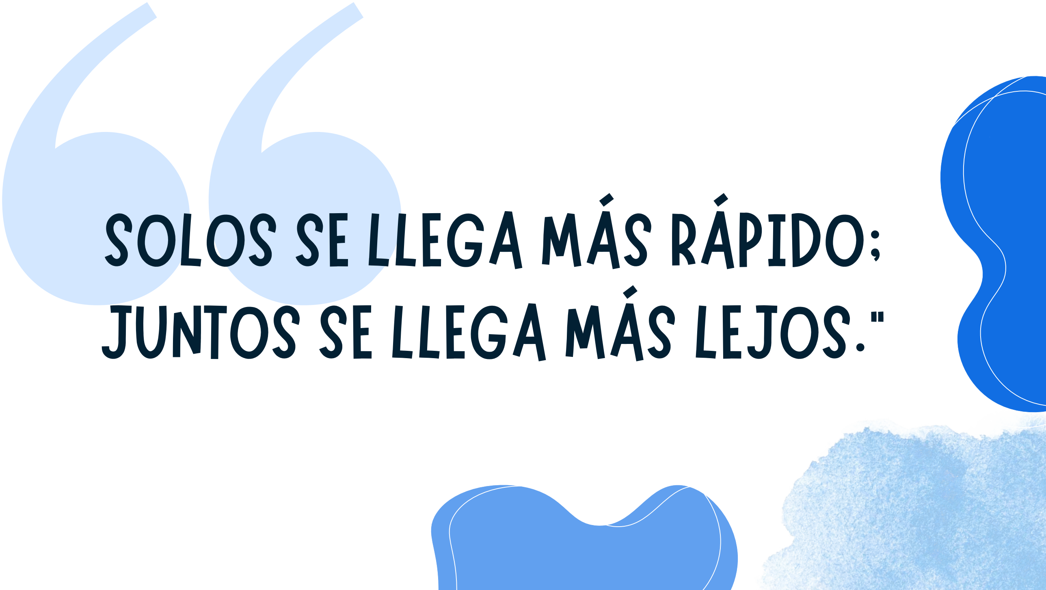
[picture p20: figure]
SOLOS SE LLEGA MÁS RÁPIDO; JUNTOS SE LLEGA MÁS LEJOS.
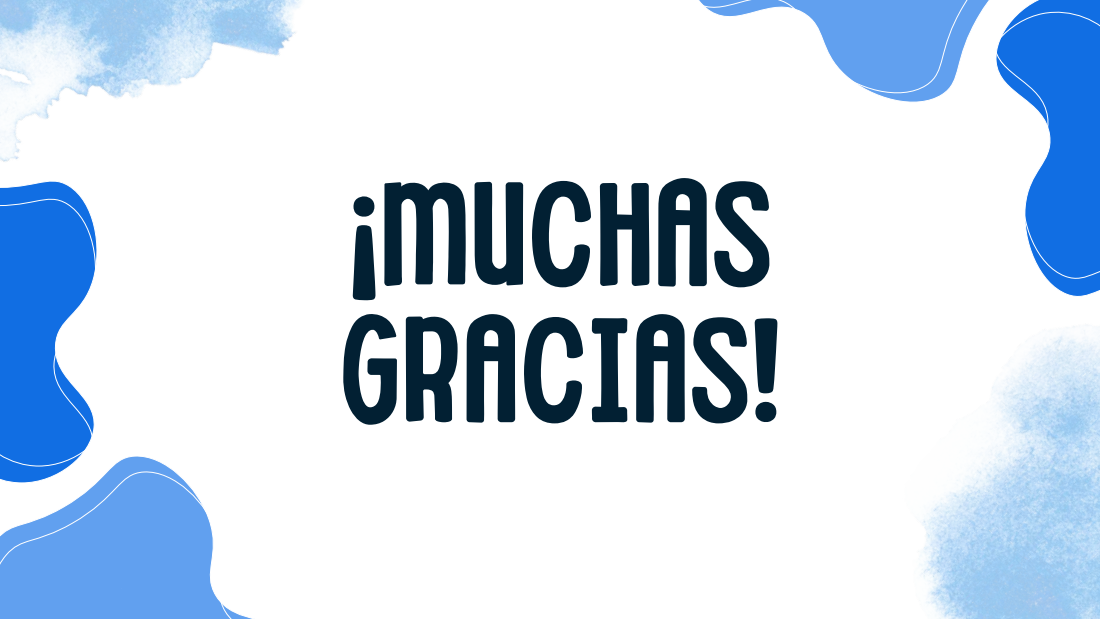
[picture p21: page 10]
¡MUCHAS GRACIAS!

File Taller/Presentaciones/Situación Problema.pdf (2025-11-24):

# PROYECTO FINAL

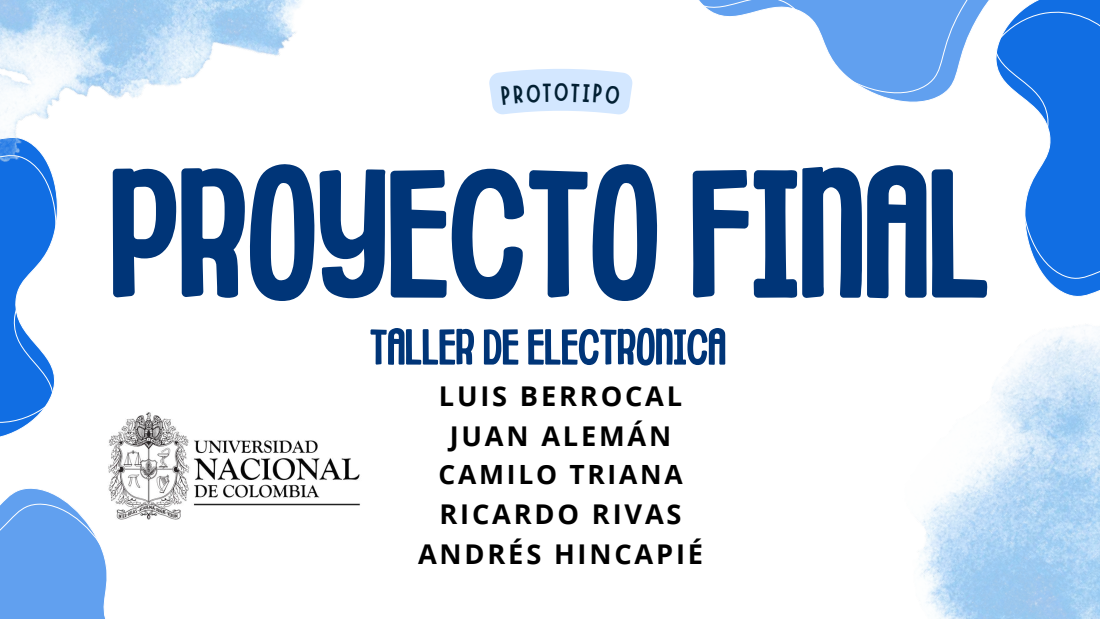
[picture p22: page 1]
TALLER DEELECTRONICA; PROTOTIPO; LUIS BERROCAL JUAN ALEMÁN CAMILO TRIANA RICARDO RIVAS ANDRÉS HINCAPIÉ

# RESUMEN DE CONTENIDOS

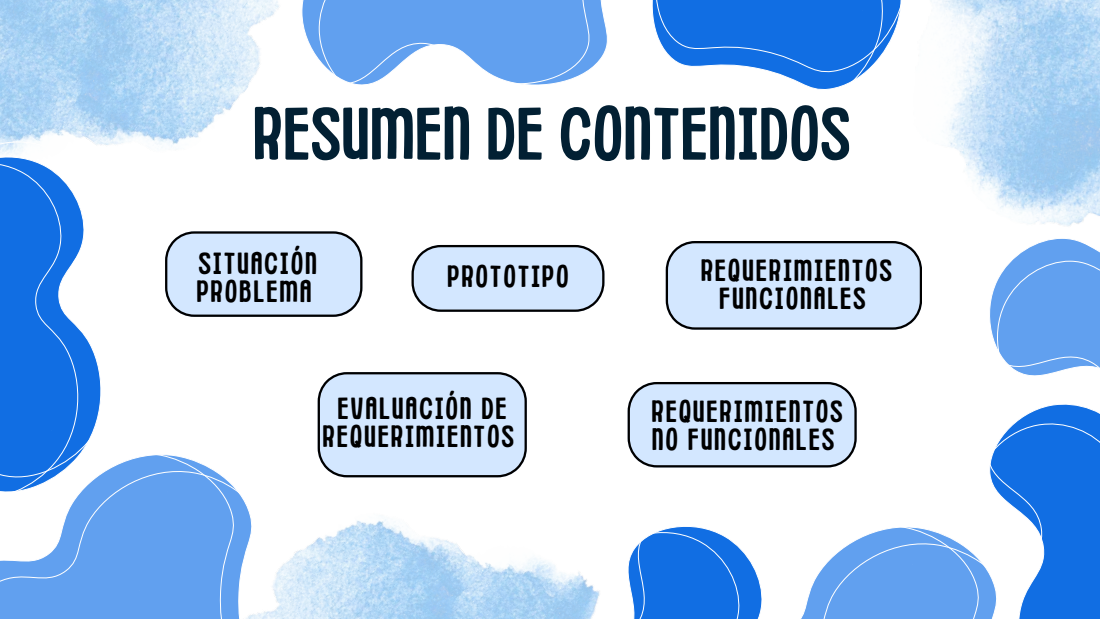
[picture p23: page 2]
EVALUACIÓN DE REQUERIMIENTOS; SITUACIÓN PROBLEMA; REQUERIMIENTOS FUNCIONALES; REQUERIMIENTOS NO FUNCIONALES; PROTOTIPO

# SITUACIÓN PROBLEMA


# SITUACIÓN PROBLEMA


Según cifras oficiales del acueducto de la ciudad, en el
2024 se reportaron alrededor de unos 89 millones de
metros cúbicos de agua desperdiciada.
De este desperdicio unos 35.58 millones de litros cúbicos
de agua se perdieron gracias a daños en las tuberías de la
ciudad.

PROTOTIPO

Para mejorar la detección temprana de daños en la red de distribución de agua potable, se desarrollará un prototipo de robot móvil con forma de carrito, diseñado para desplazarse dentro de los tubos principales de transporte. Este dispositivo estará equipado con una cámara de inspección, sensores de presión, humedad y ultrasonido, los cuales permitirán identificar rupturas, grietas o zonas estructuralmente debilitadas que representen riesgo de fuga. La información recolectada por los sensores será procesada mediante un sistema de control basado en plataformas como Arduino o Raspberry, facilitando la transmisión de datos en tiempo real a los operarios. El chasis del robot será fabricado con materiales resistentes a la humedad y sus componentes serán ensamblados utilizando herramientas de prototipado rápido como impresoras 3D y cortadoras láser. Este sistema busca
optimizar la eficiencia en la detección y mantenimiento de tuberías, reduciendo el desperdicio de | agua y
los costos | asociados a reparaciones tardías.

# PROTOTIPO

la gravedad del daño.; en caso necesario.

Detección de grietas y puntos débiles: A través de sensores ultrasónicos, cámaras y análisis de vibraciones, el sistema debe detectar fracturas, fisuras o zonas de debilitamiento estructural en las paredes internas de los tubos, clasificando el tipo y

Transmisión y registro de datos: El robot debe enviar la información recolectada a una estación externa mediante comunicación inalámbrica o por cable, almacenando los datos para su posterior análisis y mantenimiento predictivo.
Autonomía de navegación: El dispositivo debe desplazarse de manera autónoma por los conductos principales, evitando obstáculos y ajustando su velocidad según las condiciones internas del tubo, con la posibilidad de ser controlado manualmente

Sistema de alertas: Debe incluir un mecanismo de notificación que informe al personal técnico en caso de detectar anomalías críticas, pérdida de señal o fallos en los sensores, garantizando una respuesta rápida y eficaz ante posibles emergencias.

# REQUERIMIENTOS FUNCIONALES

difícil acceso.; necesidad de mantenimiento inmediato.; gestión de infraestructura.

Resistencia y durabilidad: El robot debe estar construido con materiales resistentes a la corrosión y la humedad, asegurando un funcionamiento confiable en ambientes húmedos y de

Eficiencia energética: El sistema debe optimizar el consumo de energía, utilizando baterías recargables de larga duración que permitan la operación continua durante varias horas sin

Mantenimiento y reparación sencilla: Su diseño debe facilitar el desmontaje, limpieza y reemplazo de componentes, permitiendo un mantenimiento rápido y económico. Compatibilidad y escalabilidad: El prototipo debe ser adaptable a diferentes diámetros de tuberías y configurable para integrarse con otros sistemas de monitoreo o bases de datos

# REQUERIMIENTOS NO FUNCIONALES

transmitida.; conocimientos técnicos avanzados.

Seguridad operativa: El dispositivo debe operar sin riesgo de contaminación del agua potable, garantizando que todos sus materiales y lubricantes sean seguros y no tóxicos. Confiabilidad de los datos: Los sensores y cámaras deben proporcionar mediciones precisas y estables, minimizando errores de lectura y garantizando la integridad de la información

Usabilidad: La interfaz de control y visualización de datos debe ser intuitiva, permitiendo a los operadores interpretar fácilmente los resultados y gestionar las alertas sin necesidad

Portabilidad: El robot y su sistema de control deben ser compactos y ligeros, facilitando su transporte, instalación y despliegue en diferentes puntos de la red de tuberías.
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

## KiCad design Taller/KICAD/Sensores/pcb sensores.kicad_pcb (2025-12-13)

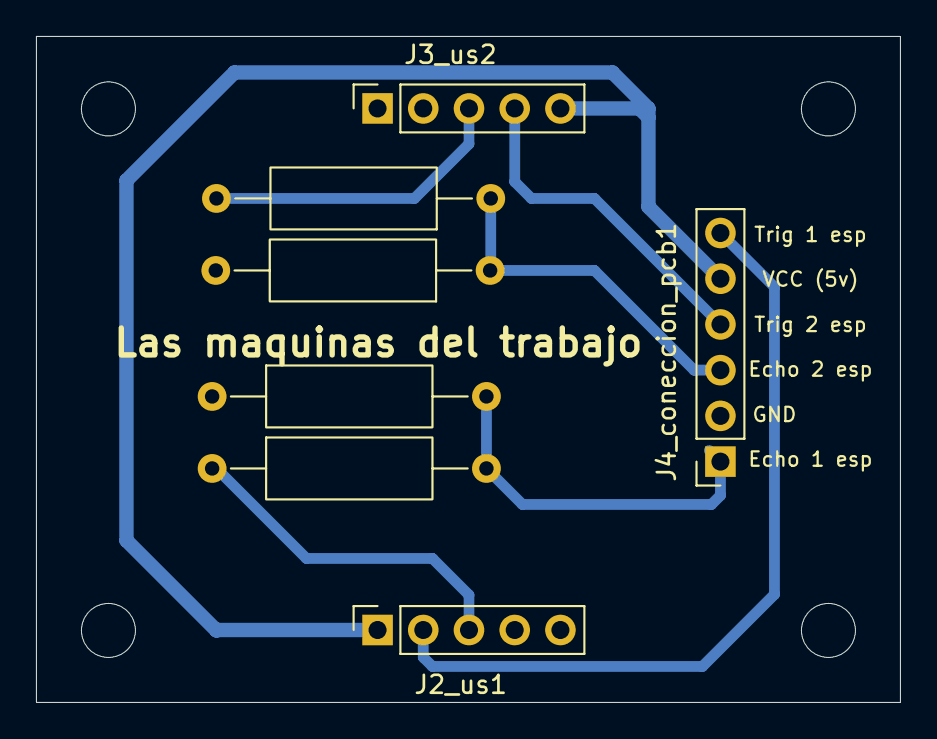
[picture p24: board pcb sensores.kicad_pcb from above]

Board: 2 copper layers, 48.0 x 37.0 mm, 7 parts (0 on the bottom side), 8 nets.

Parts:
J2_us1, J3_us2: Conn_01x05; PinSocket_1x05_P2.54mm_Vertical
J4_coneccion_pcb1: Conn_01x06; PinSocket_1x06_P2.54mm_Vertical
R1, R4: 20 KOhm; R_Axial_DIN0309_L9.0mm_D3.2mm_P15.24mm_Horizontal
R2, R3: 10 KOhm; R_Axial_DIN0309_L9.0mm_D3.2mm_P15.24mm_Horizontal

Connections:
+5V: J2_us1.1 (vcc_us1), J3_us2.5 (vcc_us2), J4_coneccion_pcb1.5
/echo1_esp: J4_coneccion_pcb1.1, R1.2, R2.2
/echo2_esp: J4_coneccion_pcb1.3, R3.1, R4.1
/trig1_esp: J2_us1.2 (trig1_raw), J4_coneccion_pcb1.6
/trig2_esp: J3_us2.4 (trig2_raw), J4_coneccion_pcb1.4
GND: J2_us1.5 (GND_us1), J3_us2.1 (GND_us2), J4_coneccion_pcb1.2, R1.1, R4.2
unnamed: J2_us1.3 (echo1_raw), R2.1
unnamed: J3_us2.3 (echo2_raw), R3.2

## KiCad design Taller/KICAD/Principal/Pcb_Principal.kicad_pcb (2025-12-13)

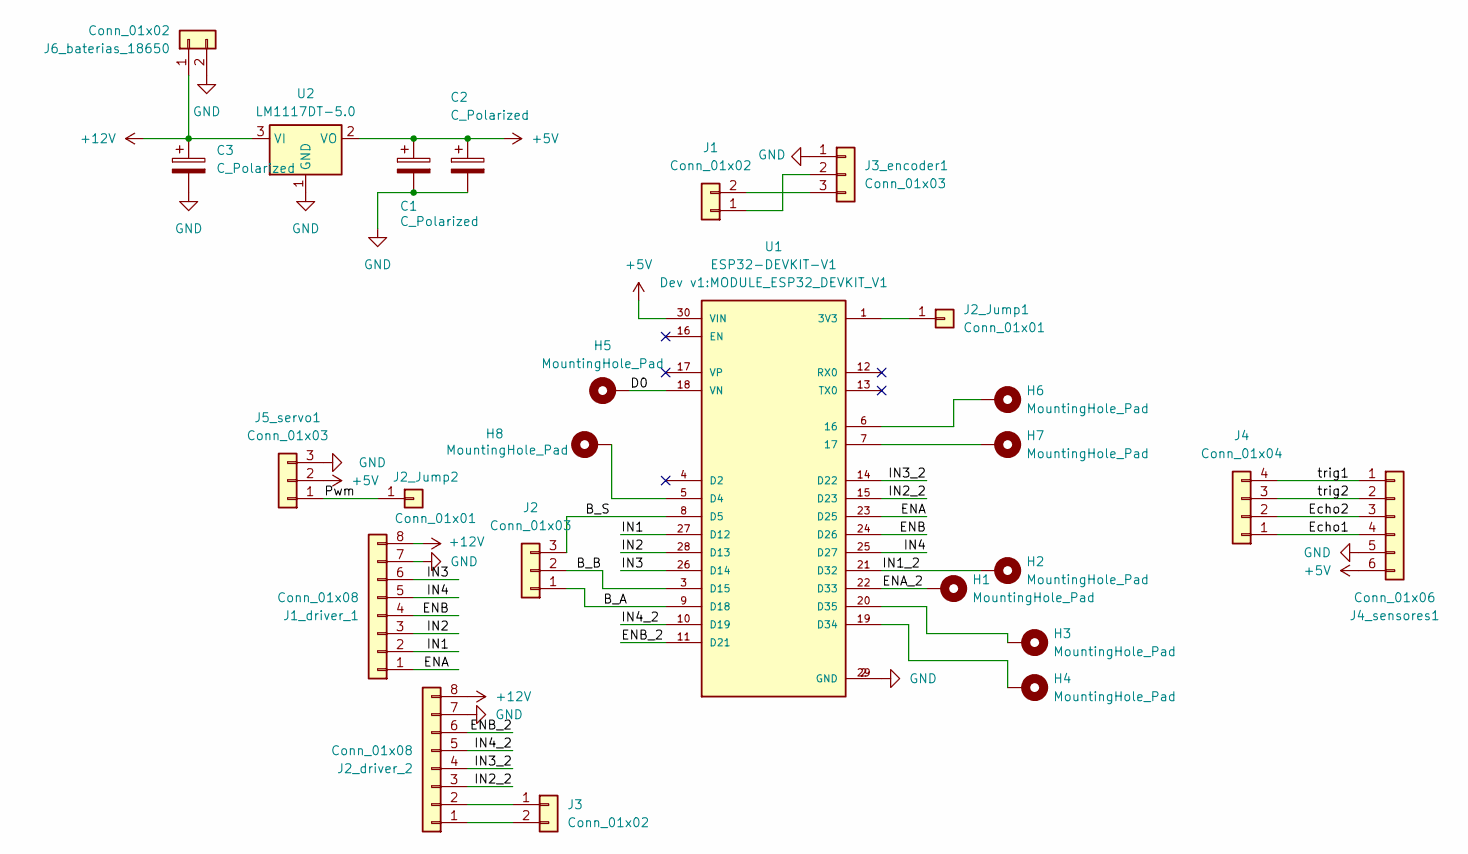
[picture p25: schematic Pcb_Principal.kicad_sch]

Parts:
C1, C2, C3: C_Polarized; CP_Radial_D5.0mm_P2.50mm
H1, H2, H3, H4, H5, H6, H7, H8: MountingHole_Pad; Pin_D1.0mm_L10.0mm
J1, J3: Conn_01x02; PinHeader_1x02_P2.54mm_Vertical
J1_driver_1, J2_driver_2: Conn_01x08; PinSocket_1x08_P2.54mm_Vertical
J2: Conn_01x03; PinHeader_1x03_P2.54mm_Vertical
J2_Jump1, J2_Jump2: Conn_01x01; PinHeader_1x01_P2.54mm_Vertical
J3_encoder1, J5_servo1: Conn_01x03; PinSocket_1x03_P2.54mm_Vertical
J4: Conn_01x04; PinHeader_1x04_P2.54mm_Vertical
J4_sensores1: Conn_01x06; PinSocket_1x06_P2.54mm_Vertical
J6_baterias_18650: Conn_01x02; PinSocket_1x02_P2.54mm_Vertical
U1: ESP32-DEVKIT-V1; MODULE_ESP32_DEVKIT_V1; PARTREV N/A
U2: LM1117DT-5.0; SIPAK_Vertical

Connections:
+5V: C1.1, C2.1, J4_sensores1.6 (s), J5_servo1.2, U1.30 (VIN), U2.2 (VO)
+12V: C3.1, J1_driver_1.8 (+12V), J2_driver_2.8 (+12V), J6_baterias_18650.1, U2.3 (VI)
/B_A: J2.1, U1.9 (D18)
/B_B: J2.2, U1.3 (D15)
/B_S: J2.3, U1.8 (D5)
/D0: H5.1, U1.18 (VN)
/ENA: J1_driver_1.1 (ENA), U1.23 (D25)
/ENA_2: H1.1, U1.22 (D33)
/ENB: J1_driver_1.4 (IN3), U1.24 (D26)
/ENB_2: J2_driver_2.6 (ENB), U1.11 (D21)
/Echo1: J4.1, J4_sensores1.4
/Echo2: J4.2, J4_sensores1.3
/IN1: J1_driver_1.2 (IN1), U1.27 (D12)
/IN1_2: H2.1, U1.21 (D32)
/IN2: J1_driver_1.3 (IN2), U1.28 (D13)
/IN2_2: J2_driver_2.3 (IN2_2), U1.15 (D23)
/IN3: J1_driver_1.6 (ENB), U1.26 (D14)
/IN3_2: J2_driver_2.4 (IN3), U1.14 (D22)
/IN4: J1_driver_1.5 (IN4), U1.25 (D27)
/IN4_2: J2_driver_2.5 (IN4), U1.10 (D19)
/Pwm: J2_Jump2.1, J5_servo1.1
/trig1: J4.4, J4_sensores1.1
/trig2: J4.3, J4_sensores1.2 (trig2)
GND: C1.2, C2.2, C3.2, J1_driver_1.7 (GND), J2_driver_2.7 (GND), J3_encoder1.1, J4_sensores1.5, J5_servo1.3, J6_baterias_18650.2, U1.2 (GND), U1.29 (GND), U2.1 (GND)
unnamed: J1.1, J3_encoder1.2
unnamed: J1.2, J3_encoder1.3
unnamed: J2_Jump1.1, U1.1 (3V3)
unnamed: J2_driver_2.1 (ENA), J3.2
unnamed: J2_driver_2.2 (IN1), J3.1
unnamed: H6.1, U1.6 (16)
unnamed: H7.1, U1.7 (17)
unnamed: H8.1, U1.5 (D4)
unnamed: H4.1, U1.19 (D34)
unnamed: H3.1, U1.20 (D35)

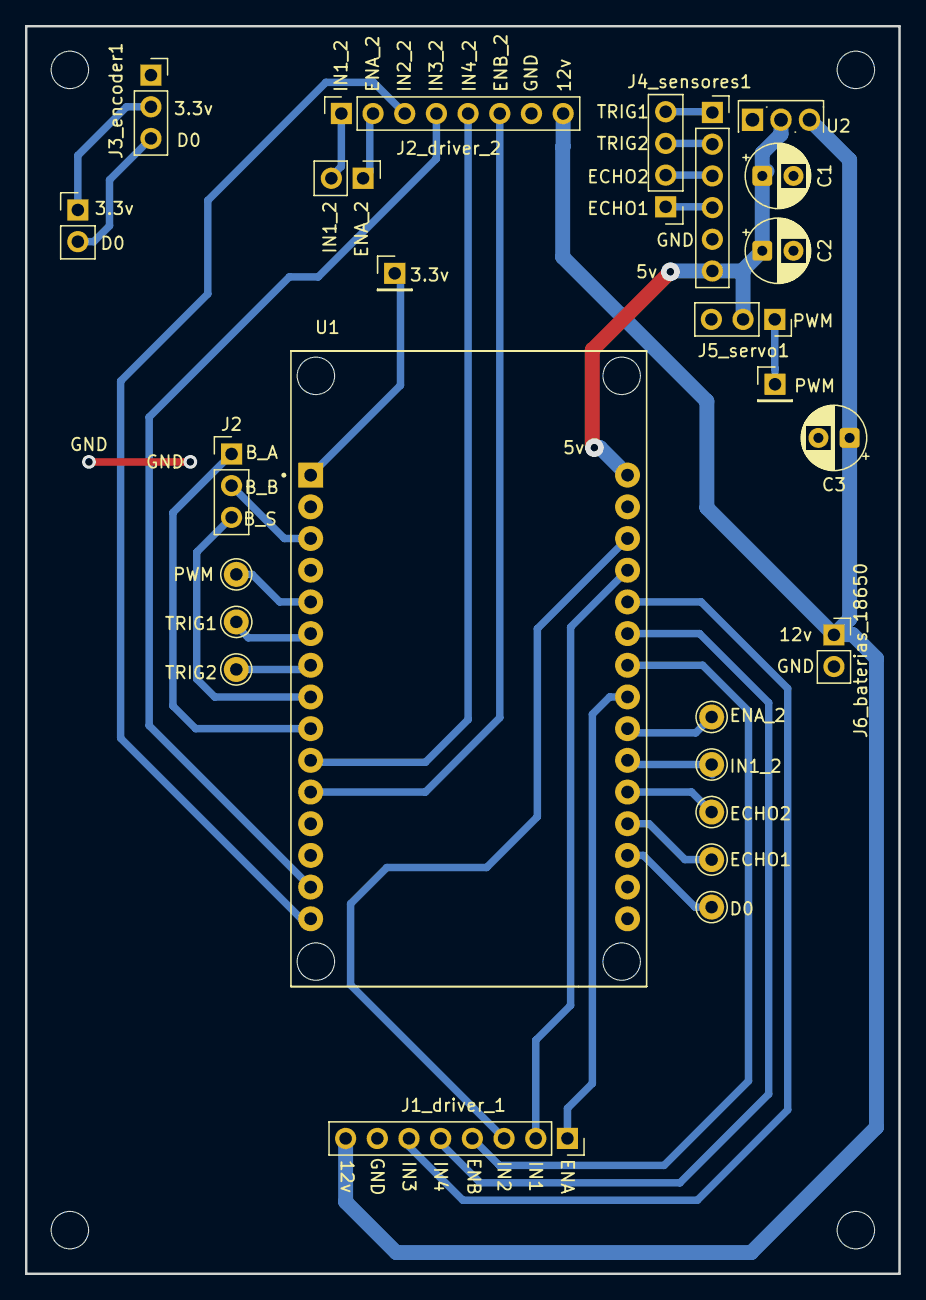
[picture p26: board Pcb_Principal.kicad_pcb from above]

Board: 2 copper layers, 70.0 x 100.0 mm, 25 parts (0 on the bottom side), 34 nets.

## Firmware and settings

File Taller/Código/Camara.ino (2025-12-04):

#include "esp_camera.h"

// Pines ESP32 Wrover Dev
#define PWDN_GPIO_NUM    -1
#define RESET_GPIO_NUM   -1
#define XCLK_GPIO_NUM    21
#define SIOD_GPIO_NUM    26
#define SIOC_GPIO_NUM    27
#define Y9_GPIO_NUM      35
#define Y8_GPIO_NUM      34
#define Y7_GPIO_NUM      39
#define Y6_GPIO_NUM      36
#define Y5_GPIO_NUM      19
#define Y4_GPIO_NUM      18
#define Y3_GPIO_NUM      5
#define Y2_GPIO_NUM      4
#define VSYNC_GPIO_NUM   25
#define HREF_GPIO_NUM    23
#define PCLK_GPIO_NUM    22

void setup() {
  Serial.begin(921600); // 2 Mbps para mejor FPS

  camera_config_t config;
  config.ledc_channel = LEDC_CHANNEL_0;
  config.ledc_timer = LEDC_TIMER_0;
  config.pin_d0 = Y2_GPIO_NUM;
  config.pin_d1 = Y3_GPIO_NUM;
  config.pin_d2 = Y4_GPIO_NUM;
  config.pin_d3 = Y5_GPIO_NUM;
  config.pin_d4 = Y6_GPIO_NUM;
  config.pin_d5 = Y7_GPIO_NUM;
  config.pin_d6 = Y8_GPIO_NUM;
  config.pin_d7 = Y9_GPIO_NUM;
  config.pin_xclk = XCLK_GPIO_NUM;
  config.pin_pclk = PCLK_GPIO_NUM;
  config.pin_vsync = VSYNC_GPIO_NUM;
  config.pin_href = HREF_GPIO_NUM;
  config.pin_sscb_sda = SIOD_GPIO_NUM;
  config.pin_sscb_scl = SIOC_GPIO_NUM;
  config.pin_pwdn = PWDN_GPIO_NUM;
  config.pin_reset = RESET_GPIO_NUM;
  config.xclk_freq_hz = 20000000;
  config.pixel_format = PIXFORMAT_JPEG;

  config.frame_size = FRAMESIZE_QVGA;   // 320x240
  config.jpeg_quality = 14;
  config.fb_count = 2;

  if (esp_camera_init(&config) != ESP_OK) {
    Serial.println("Camera init failed");
    return;
  }
}

void loop() {
  camera_fb_t *fb = esp_camera_fb_get();
  if (!fb) return;

  // Delimitadores
  Serial.println("FRAME_START");
  Serial.write(fb->buf, fb->len);
  Serial.println("\nFRAME_END");

  esp_camera_fb_return(fb);

  delay(5); // para evitar saturar el puerto (ajustable)
}

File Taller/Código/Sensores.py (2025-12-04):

from machine import Pin, PWM
from machine import Pin, time_pulse_us
import time


# === Pines del Sensor 1 ===
TRIG1 = Pin(16, Pin.OUT)
ECHO1 = Pin(34, Pin.IN)

# === Pines del Sensor 2 ===
TRIG2 = Pin(17, Pin.OUT)
ECHO2 = Pin(35, Pin.IN)

# Pin donde conectar la señal del servo
servo = PWM(Pin(4), freq=50)

# Función genérica para medir distancia en un sensor
def medir_distancia(TRIG, ECHO):
    # Asegurar TRIG en LOW
    TRIG.value(0)
    time.sleep_us(5)

    # Enviar pulso
    TRIG.value(1)
    time.sleep_us(10)
    TRIG.value(0)

    # Medir tiempo del pulso en ECHO
    duracion = time_pulse_us(ECHO, 1, 30000)

    if duracion < 0:
        return None

    distancia = (duracion / 2) * 0.343
    return distancia
# Conversión de grados a duty_us (microsegundos)
def set_angle(angle):
    # MG90S normalmente usa 500-2400 us
    min_us = 500
    max_us = 2400
    us = min_us + (angle / 180) * (max_us - min_us)
    servo.duty_u16(int(us * 65535 / 20000))  # 20 ms period
    time.sleep(0.02)
set_angle(0)
print("servo en angulo 0")
time.sleep(5)

def Show_SensorU():
    #Sensor 1
    d1 = medir_distancia(TRIG1, ECHO1)
    time.sleep_ms(20)  # pequeño delay para evitar interferencias

    #Sensor 2
    d2 = medir_distancia(TRIG2, ECHO2)
    time.sleep_ms(10)
    
    print("Sensor 1:", "Sin lectura" if d1 is None else f"{round(d1,2)} mm")
    print("Sensor 2:", "Sin lectura" if d2 is None else f"{round(d2,2)} mm")
    time.sleep(0.1)
# Movimiento de prueba
while True:
    for ang in range(0, 201, 5):
        set_angle(ang)
        time.sleep(0.02)
        Show_SensorU()
        print(ang)

    for ang in range(200, -1, -5):
        set_angle(ang)
        time.sleep(0.02)
        Show_SensorU()
        print(ang)

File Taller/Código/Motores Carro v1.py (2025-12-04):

from machine import Pin, PWM
import time

# --------------------------
# Motor A (L298N #1)
# --------------------------
ena = PWM(Pin(25), freq=500)
in1 = Pin(12, Pin.OUT)
in2 = Pin(13, Pin.OUT)

# --------------------------
# Motor B (L298N #1)
# --------------------------
enb = PWM(Pin(26), freq=500)
in3 = Pin(14, Pin.OUT)
in4 = Pin(27, Pin.OUT)

# --------------------------
# Motor C (L298N #2)
# --------------------------
enc = PWM(Pin(33), freq=500)
in5 = Pin(32, Pin.OUT)
in6 = Pin(23, Pin.OUT)

# --------------------------
# Motor D (L298N #2)
# --------------------------
end = PWM(Pin(21), freq=500)
in7 = Pin(22, Pin.OUT)
in8 = Pin(19, Pin.OUT)

# --------------------------
# Funciones básicas
# --------------------------

def motors_forward(speed=700):
    print("4 motores avanzando...")

    # Motor A
    in1.value(0); in2.value(1); ena.duty(speed)
    # Motor B
    in3.value(0); in4.value(1); enb.duty(speed)
    # Motor C
    in5.value(1); in6.value(0); enc.duty(speed)
    # Motor D
    in7.value(1); in8.value(0); end.duty(speed)


def motors_backward(speed=700):
    print("4 motores retrocediendo...")

    # Motor A
    in1.value(1); in2.value(0); ena.duty(speed)
    # Motor B
    in3.value(1); in4.value(0); enb.duty(speed)
    # Motor C
    in5.value(0); in6.value(1); enc.duty(speed)
    # Motor D
    in7.value(0); in8.value(1); end.duty(speed)


def motors_stop():
    print("Deteniendo los 4 motores...")

    ena.duty(0); enb.duty(0); enc.duty(0); end.duty(0)

    in1.value(0); in2.value(0)
    in3.value(0); in4.value(0)
    in5.value(0); in6.value(0)
    in7.value(0); in8.value(0)

# --------------------------
# Prueba simple
# --------------------------

print("Prueba de 4 motores...")

motors_forward(700)
time.sleep(3)

motors_stop()
time.sleep(1)

motors_backward(700)
time.sleep(3)

motors_stop()
print("Fin de prueba.")
